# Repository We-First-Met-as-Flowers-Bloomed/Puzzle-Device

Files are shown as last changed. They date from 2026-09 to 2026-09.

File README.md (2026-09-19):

# Puzzle Device｜AI 视觉自动拼图装置

面向 2026 年电子设计竞赛 E 题要求设计的自动拼图实验装置。系统以 MaixCAM2 完成 A4 工作区识别、碎片检测、拼图求解和目标位姿计算，以 STM32F407 完成四轴运动、吸取、旋转和放置。人工完成上电和启动操作后，装置自动执行后续流程。

> 本仓库记录参赛原型的软硬件实现，适合电子设计竞赛复盘、机器视觉与运动控制教学，以及自动控制综合实验参考。实际复现时必须按自己的相机安装位置、机械原点和脉冲当量重新标定。

## 演示视频

项目运行效果已发布到 Bilibili：

- [观看 E 题装置演示与项目动态](https://space.bilibili.com/234483320/dynamic?spm_id_from=333.1387.list.card_title.click)
- 文字说明见 [Demo/README.md](Demo/README.md)

## 系统组成

```mermaid
flowchart LR
    A[上电并等待初始化] --> B[按下 MaixCAM2 启动键]
    B --> C[视觉检测与拼图求解]
    C --> D[生成拾取/放置坐标与旋转角]
    D --> E[UART JSONL 发送至 STM32F407]
    E --> F[四轴运动与电磁铁吸放]
    F --> G{全部碎片完成?}
    G -- 否 --> F
    G -- 是 --> H[声光提示/实验结束]
```

核心模块包括：

- **视觉感知**：检测 A4 纸、分界线和 1—4 块拼图碎片。
- **拼图求解**：计算合法矩形组合、各碎片目标位置和旋转角度。
- **坐标转换**：将相机坐标转换为机构坐标，再转换为绝对脉冲位置。
- **运动执行**：STM32F407 控制 X、Y、Z、R 四轴和电磁铁完成抓取与放置。
- **一键运行**：装置初始化后，由相机端启动键触发一次完整任务。

## 仓库结构

```text
Puzzle-Device/
├── README.md
├── LICENSE
├── Firmware/
│   ├── STM32F407/          # STM32CubeMX/HAL 运动控制工程
│   └── MaixCAM2-Vision/    # AI视觉、拼图求解和坐标输出
├── Hardware/
│   ├── Schematic/          # 嘉立创EDA工程文件
│   ├── PCB/                # PCB资料状态说明
│   └── BOM/                # 元器件清单状态说明
├── Mechanical/
│   ├── STEP/               # STEP资料状态说明
│   └── STL/                # 3D打印模型
├── Docs/
│   ├── System-Design/      # 系统与固件设计资料
│   └── Images/             # 项目图片预留目录
└── Demo/                   # 演示视频入口与操作流程
```

## 快速开始

### 1. 准备工具

- STM32CubeMX 和 Keil MDK-ARM（STM32F407 工程）。
- MaixVision、与设备系统匹配的 MaixCAM2 Runtime。
- 嘉立创EDA专业版（打开 `.eprj2` 工程）。
- 3D 打印机或可读取 STL 的切片软件。
- 3.3 V TTL 串口连接，MaixCAM2 TX/RX 与 STM32 RX/TX 交叉并共地。

### 2. 编译并烧录 STM32F407

1. 进入 [`Firmware/STM32F407`](Firmware/STM32F407)。
2. 可用 STM32CubeMX 打开 `Automatic inspection vehicle.ioc` 查看和重新生成外设配置。
3. 用 Keil 打开 `MDK-ARM/Automatic inspection vehicle.uvprojx`。
4. 选择 STM32F407 对应目标，编译并通过调试器烧录。
5. 首次运动前断开电机负载，检查限位、轴方向、回零逻辑和急停条件。

### 3. 部署 MaixCAM2 视觉程序

1. 进入 [`Firmware/MaixCAM2-Vision`](Firmware/MaixCAM2-Vision)。
2. 将 `config.example.json` 复制为 `config.json`。
3. 使用标定工具生成相机内参和 `frame_to_robot` 变换；确认无误后再设置 `robot_calibrated=true`。
4. 使用 MaixVision 打开整个项目目录并选择“运行项目”，不要只上传 `main.py`。
5. 验证识别和串口输出后，可通过“安装应用”部署，并在设备设置中配置开机启动。

视觉端详细参数、标定命令、UART协议和测试方法见 [MaixCAM2 说明](Firmware/MaixCAM2-Vision/README.md)。

### 4. 接线和联调

1. 保持电机驱动关闭，先验证 MaixCAM2 与 STM32 的串口接线。
2. 使用视觉工程中的 `tools/uart_smoke_test.py` 发送固定测试消息。
3. 检查 STM32 能完整接收一行 JSONL，并确认不会在半包数据到达时启动机构。
4. 分别验证 X、Y、Z、R 轴方向、软硬限位、回零和电磁铁吸放。
5. 低速空载运行完整流程，再安装拼图碎片进行测试。

### 5. 正常操作

1. 放置符合题目范围的 A4 工作区和拼图碎片，确保完整纸边与分界线均在相机画面内。
2. 给装置上电，等待 STM32、驱动器和视觉模块初始化完成。
3. 按下 MaixCAM2 界面中的 `START`。
4. 系统自动识别碎片、规划目标位姿，并依次完成抓取、移动、旋转和放置。
5. 运行过程中不要移动相机、A4 纸或机械结构，也不要进入机构运动范围。

## 关键配置

视觉端默认以 `1280×720`、30 fps 取帧，通过 `/dev/ttyS2`、115200 baud 向主控发送 JSONL。示例动作如下：

```json
{
  "piece_id": 0,
  "pickup_x_pulse": 9600,
  "pickup_y_pulse": 7200,
  "place_x_pulse": 18000,
  "place_y_pulse": 12800,
  "rotation_deg": 30.0
}
```

这些脉冲值仅用于说明协议。更换相机、安装高度、传动机构、驱动细分或机械原点后，必须重新测量并修改配置。

## 资料完整性

当前仓库包含 STM32 与 MaixCAM2 源码、嘉立创EDA工程和三件 STL 模型。PCB Gerber、独立 BOM 和 STEP 模型尚未整理，因此对应目录暂以说明文件占位。欢迎根据原理图和实际装配补充并提交 Pull Request。

## 测试

视觉模块的基础标定测试不需要真实相机：

```powershell
cd Firmware/MaixCAM2-Vision
python -m unittest tests.test_calibration_points -v
```

`tests.test_vision` 中的大部分测试可以直接运行，但部分实拍回归测试依赖未随当前开源包发布的现场图片和本机标定配置，详见 [`tests/README.md`](Firmware/MaixCAM2-Vision/tests/README.md)。STM32 工程的 `tests/` 包含主机端 C 测试和策略检查脚本，可在 Windows/PowerShell 环境按需运行。真实硬件的方向、限位、回零、标定精度和急停仍需逐项实测。

## 开源许可

项目采用 [MIT License](LICENSE)。第三方 STM32 HAL、CMSIS 及其他依赖仍遵循其各自许可证。

## 致谢与交流

如果这个项目对你的电子设计竞赛、自动控制实验或机器视觉学习有帮助，欢迎 Star、Fork、提交 Issue 或 Pull Request。也可以通过上方 Bilibili 页面查看演示并交流复现经验。

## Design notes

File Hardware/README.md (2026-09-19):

# Hardware

`Schematic/` 中提供嘉立创EDA专业版工程文件。当前版本尚未单独导出 PCB Gerber 与正式 BOM；`PCB/` 和 `BOM/` 中的说明用于记录这一资料状态。

制作硬件前请根据所用驱动器、电机、电磁铁、供电和接口定义复核原理图，尤其注意逻辑电平、共地、驱动电流和急停设计。

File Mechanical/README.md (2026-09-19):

# Mechanical

`STL/` 提供当前整理出的齿轮、齿条和约束装置模型，可直接导入切片软件。打印前请根据自己的导轨、同步机构、轴径、公差和材料收缩率检查尺寸。

当前未提供 STEP 装配模型，状态说明见 `STEP/README.md`。

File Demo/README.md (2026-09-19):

# Demo

## 在线观看

[前往 Bilibili 查看 E 题装置演示与相关动态](https://space.bilibili.com/234483320/dynamic?spm_id_from=333.1387.list.card_title.click)

## 演示流程

1. 给装置上电并等待初始化。
2. 在视觉模块上按下启动键。
3. AI视觉模块分析碎片当前位置，求解目标位置与旋转角。
4. STM32 控制四轴和电磁铁依次完成吸取、移动、旋转和放置。
5. 相同过程循环执行，直到所有碎片拼接完成。

演示所用装置针对题目规定的材料、尺寸、数量和工作区条件设计。超出题目范围的碎片、摆放方式或光照条件未作为该原型的能力保证。

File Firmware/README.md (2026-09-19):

# Firmware

- `STM32F407/`：四轴运动、电磁铁、限位、回零、串口协议和任务状态机。
- `MaixCAM2-Vision/`：图像采集、碎片分割、拼图求解、坐标标定和 UART JSONL 输出。

先分别验证视觉输出与各轴运动，再进行串口联调和完整装置测试。

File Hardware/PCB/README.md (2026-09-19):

# PCB

当前开源包尚未提供独立的 Gerber、钻孔和贴片坐标文件。可使用 `../Schematic/STM32F407VGT6-Motion-Control.eprj2` 在嘉立创EDA专业版中查看现有工程并按实际版本导出。

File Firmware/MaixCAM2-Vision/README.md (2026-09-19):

# MaixCAM2 E 题拼图视觉

当前版本：`0.2.48`

白色自备碎片和白底扑克牌会先尝试经过数量、面积及 3～5 边形
规则验证的快速 Lab 分割；不满足条件的彩色碎片、低饱和度纸面或
复杂光照场景自动使用原有的自适应光照平面分割。

这套代码完成以下板端视觉链路：

1. 自动检测完整 A4 外轮廓并做透视校正；
2. 在 Lab 颜色空间检测规定的中部分界线；
3. 自动把有碎片的一侧旋转为纸面坐标的上半区；
4. 用纯色 A4 的背景模型分割 1–4 片直边碎片；
5. 提取多边形、质心和距离边界最远的稳定吸取点；
6. 先按边长、端点补角和直角/外边界先验建立候选图，枚举四片的全部全局连接树，再用 T 接点搜索补充；
7. 支持完整共边、长边内部偏移和一条长边被多片分段拼接的 T 接缝；
8. 自动区分纯色片与印刷片，只对扑克牌用跨接缝 Lab 颜色/梯度连续性消歧；
9. 把矩形居中放入 A4 下半区安全范围，输出每片吸取点、放置点和旋转量；
10. 可选地把 A4 毫米坐标映射为运动机构毫米坐标，并通过 UART 输出 JSON。

算法不需要网络、电脑端推理、AprilTag、额外定位线、补光或遮光板。比赛运行时只使用
MaixCAM2、板载 OpenCV/NumPy、A4 边界、规定分界线和碎片本身。

## 目录

```text
main.py                         MaixCAM2 横屏触控运行入口
config.json                     板端安全默认配置
config.example.json             参数与坐标标定示例副本
puzzle_vision/detector.py       A4、中线、背景和碎片检测
puzzle_vision/template_solver.py 图 2 固定四片的有界模板求解
puzzle_vision/solver.py         几何搜索及扑克牌接缝评分
puzzle_vision/pipeline.py       目标落位、指令输出和可视化
tools/run_image.py              PC 端回放一张实拍图
tools/calibrate_camera.py       赛前镜头内参标定
tools/collect_calibration_points.py 鼠标点选像素并录入机构坐标
tools/fit_frame_to_robot.py     固定相机像素到机构坐标标定
tools/uart_smoke_test.py        UART2 固定 JSON 发包测试
tests/                          图 2、透视和横向摆纸合成测试
```

## 0.2.48 扑克牌求解轮廓的毫米级稳定化

- 扑克牌检测结果仍保留原始毫米坐标、吸取点和面积；仅送入组合求解器的多边形顶点取整到 1 mm，消除相邻帧约 0.3～0.7 mm 的轮廓抖动。
- 本次 Q♠ 连续两帧由“一帧成功、一帧两轮失败”恢复为稳定的唯一矩形候选。

## 0.2.47 固定红纸的阴影粘连抑制

- 固定标定且纸面颜色饱和时，完整分割改用色度差作为前景，避免只有亮度变化的红纸阴影与真实碎片粘连。
- 本次 Q♠ 实拍中的 2908 mm² 贴边伪五边形恢复为独立真实碎片，防止两轮求解在错误轮廓上耗尽时间。

## 0.2.46 固定纸框外边缘伪碎片过滤

- 当颜色分割产生超过 4 个有效多边形时，优先去除贴住纸张上、左、右外边界的光照区域；只有过滤后仍得到 1～4 片才采用该结果。
- 本次 Joker 实拍中的两个右边缘伪轮廓被去除，真实四个碎片保持不变。

## 0.2.45 三片拼图的二次 T 接缝搜索

- 三片扑克牌首次通用搜索失败后，现在会进入二次覆盖搜索，不再把 1～3 片一律视为无需重试的确定性路径。
- 两片已经放置后，三片模式也会按局部轮廓紧凑度筛选扩展的 T 接缝候选，避免正确的长边内部拼接被候选上限截掉。
- 本次 3 片 6♣ 实拍保持原检测轮廓，状态由 `SolveError` 恢复为 `OK`；PC 端检测加两轮求解约 `0.6 s`，有效候选为 1。

## 0.2.44 三片扑克牌的双切边印花恢复

- 修复 `expected_piece_count=0` 时，白色快速分割把两个有效轮廓当作完整结果返回、忽略第三个
  “面积达到碎片范围但因双切边印花而未通过多边形修复”的轮廓。现在只要存在这种被拒绝的
  碎片大小连通域，就回退到包含黑色牌面图案的完整 Lab 颜色分割。
- 本次 3 片 10♠ 实拍由错误的 2 片恢复为 3 片，面积约为 `1240、1849、2154 mm²`；
  通用求解只需约 `65 ms`，填充率约 `0.955`、四边覆盖约 `0.950`。
- 通用求解的最终候选改用已有的全局刚体等价判断去重。同一相对装配仅因整体平移/旋转不同
  不再被当成两个低分差答案；目标落位仍会在下半区统一居中，真正不同的片间相对关系不会合并。
- 实拍端到端状态由 `ERROR/LOW_MARGIN` 恢复为 `OK`；上一版四条 8♠ 强阴影回归仍为 `OK`，
  分差约 `0.077`。当前可执行视觉测试为 74 项通过、标定测试为 3 项通过，另有 10 项
  历史实拍测试因 `tests/data` 原图缺失而未执行。

## 0.2.43 全切边印花条带与强光阴影分离

- 修复四条扑克牌的每条切边都被黑色花色切出缺口时，白色牌面快速分割被整体放弃的问题。
  旧路径随后会把右上强光/阴影区域拟合成约 `7943 mm²` 的假五边形，并漏掉真正的第四条牌片。
- 仅当白色掩膜得到 4 个同宽、总高符合整牌比例的条带，而且四个轮廓都需要印花缺口修复时，
  才用各条带的最小外接矩形恢复物理切边；普通不规则碎片和正常实测轮廓仍沿用原路径。
- 给这类重建边界增加显式标记。专用条带求解仅对标记后的轮廓从边界内侧 `3..5 mm`
  采样接缝纹理，避免误读矩形外的红纸；其他牌片继续使用原来的 `1..3 mm`，防止全局参数回归。
- 本次 8♠ 原图由两轮通用搜索失败恢复为 `OK`：正确检出 4 个约 `1139..1448 mm²`
  的矩形条带，只评估 384 个牌面顺序，PC 检测加求解约 `1.64 s`，分差约 `0.077`。
- 新增全切边缺口的合成回归；当前可执行视觉测试为 73 项通过、标定测试为 3 项通过，
  另有 10 项历史实拍测试因 `tests/data` 原图缺失而未执行。

## 0.2.42 固定标定碎片总面积容差一致化

- 修复固定纸面标定的最终面积校验比候选预检和完整分割验证更严格的问题：原先其范围为
  目标面积的 `85%..115%`，其余两处均为 `75%..125%`，导致同一画面在固定机位路径反而被提前拒绝。
- 板端本次测得的 `14695 mm²` 高于旧上限 `13656 mm²`，但低于统一后的上限 `14844 mm²`，
  因此现在可以继续进入碎片几何与求解验证，而不会在固定标定入口误报 `DetectionError`。
- 新增固定标定合成回归，复现 `14557 mm²` 的同区间场景；当前可执行视觉测试为 72 项通过，
  标定测试为 3 项通过，另有 10 项历史实拍测试因 `tests/data` 原图缺失而未执行。

## 0.2.41 论文驱动的四条扑克牌重组

- 四个同宽矩形条带不再进入通用 C1/C2 几何搜索。新分支先把每条牌片校正到局部坐标，
  为每个方向建立有向相邻边代价矩阵，再组合整牌顺序；普通随机多边形、Figure-2 和纯色碎片路径不变。
- 接缝代价采用双向一阶边界预测与沿切口方向的梯度连续性，并允许 `±2 mm` 的只读采样偏移；
  绝对误差再按每条源边和目标边的四分位数归一化，避免空白白边天然压过真正的印花连续边。
- 把互为最近邻的接缝作为 `best-buddy` 可靠性证据，同时检查牌面两个角码是否位于对角。
  最终只需评估 `4!×2^4=384` 个由相邻边矩阵评分的整牌顺序；矩形几何只负责硬验收，不再主导牌面排序。
- 两张当前可用的 8♠ 现场原图均返回 `OK`：此前 `LOW_MARGIN` 的一张分差由 `0` 提高到约 `0.075`，
  另一张保持正确顺序且分差约 `0.105`；PC 检测加求解约 `0.9–1.8 s`，均为 384 个轻量顺序。
- 方法依据包括 Pomeranz 等人的预测兼容度与四分位归一化、Gallagher 的梯度兼容度、
  Son 等人的方向导数兼容度，以及条带碎纸重组的有向代价矩阵：
  [CVPR 2011](https://www.cs.bgu.ac.il/~ben-shahar/Publications/2011-Pomeranz_Shemesh_and_Ben_Shahar-A_Fully_Automated_Greedy_Square_Jigsaw_Puzzle_Solver.pdf)、
  [CVPR 2012](https://chenlab.ece.cornell.edu/people/Andy/Andy_files/Gallagher_cvpr2012_puzzleAssembly.pdf)、
  [CVPR 2016](https://openaccess.thecvf.com/content_cvpr_2016/html/Son_Solving_Small-Piece_Jigsaw_CVPR_2016_paper.html)、
  [CVPR 2020 论文与代码](https://github.com/thiagopx/deeprec-cvpr20)。
- 当前工作区可执行的 71 项视觉测试和 3 项标定测试全部通过；另有 10 项历史实拍测试因
  `tests/data` 图像未保留在当前工作区而无法执行。两张本轮现场原图已单独完成端到端回放。

## 0.2.40 固定纸面标定、面积自适应落位与复杂牌面精修

- 当前固定相机直接使用 `config.json` 中实测的 `fixed_paper_quad_px`：
  `[(398.55,27.0), (1124.65,27.35), (1100.8,543.42), (392.73,538.18)]`。
  每轮不再重新猜测红色 A4 外框，也不使用黑色中心线决定纸框或朝向；校正后的分界线固定为纸面中心。
  若相机、镜头、分辨率或红纸位置发生移动，必须重新测量这四点，不能继续沿用旧坐标。
- 放置外扩量由统一 `3 mm` 改为面积自适应：
  `3*sqrt(四片面积中位数/当前片面积)`，并限制在 `2..5 mm`。小片获得更大装配余量，
  大片保持更接近理论位置；等面积切片仍为 `3 mm`。
- 求解搜索按碎片面积从小到大扩展，优先利用小片较强的接缝约束来压缩候选；
  机械执行则按面积从大到小放置，先建立稳定基准，最后填入小片，避免后放的大块扫动已落位小块。
- 第二轮对 J/Q/K/大小王等复杂牌面使用与首轮不同的 `2.5 mm` 缝线共线容差，并对已接近矩形的
  完整拓扑执行有界平移/旋转坐标下降；精修后仍须重新通过填充、重叠、孔洞、边界、四边覆盖、
  凸性和四角误差的严格验收，不以“看起来像矩形”代替资格检查。
- `E:\桌面\figures` 中 Q、大小王、K、J 四张 `1280×720` 实拍原图已固化为自动回归：
  均稳定检出 4 片并返回完整解；本轮可执行回归为 77 项全部通过，另有 7 项历史现场测试因其旧图片
  不在当前工作区而未执行。

## 0.2.39 四条扑克牌整牌排序与纸张候选修复

- 修复 1280×720 输入被先缩到 1100 像素、再缩到约 1 px/mm 预检时，窄牌片消失的问题；
  A4 候选的几何检测仍在有界缩略图上运行，但碎片数量/面积预检改用原始帧像素。
- 避免把黑色分隔线左侧的半张红纸误认成完整 A4；最新 8♠ 实拍由错误的约 294 px
  半纸宽恢复为约 740 px 整纸宽，中线覆盖率由 `0.29` 回升到 `0.63`。
- 新增四条同宽、不要求等面积的扑克牌分割识别。此类候选不再只按局部接缝或矩形外形排序，
  而是使用整牌 180°对应关系、对角角码和中心花色布局评分。
- 条带牌片的均衡种子容量由 6 提高到 24，覆盖四条的正确相邻关系；整牌特征权重提高到
  `0.60`。若最佳矩形的整牌特征仍不成立，则强制返回 `LOW_MARGIN`。
- 最新 8♠ 现场帧 PC 端检测加求解约 `1.6–1.8 s`，求解 170 个节点，分差约
  `0.202`；新增真实帧和不等高合成条带回归。

## 0.2.38 四等分扑克牌整牌特征求解

- 新增四等分扑克牌识别：仅当四块均为近似矩形、面积比不超过 `1.18`、对应边长差不超过
  `15%` 时启用专用路径，不改变普通随机切片和纯色拼图。
- 不再接受第一个几何矩形。专用路径去除整牌 180°全局等价后，有界枚举 192 种象限与朝向
  组合，并按整张牌面的归一化 Lab 印刷特征排序。
- 整牌判据同时使用跨象限图案、180°对应关系、对角角码分布，以及中心花色相对扑克牌长轴
  的方向；牌面权重只在四等分专用路径中提高。
- 若所有排列都只能拼出矩形、但牌面图案本身无法区分，`score_margin` 会低于默认 `0.012`，
  管线返回 `LOW_MARGIN`，不会向运动主控下发任意排列。
- 192 种布局先做稀疏整牌评分，仅对前 12 个执行严格栅格矩形验收；合成样例 PC 求解约
  `0.52–0.62 s`。
- 7 张既有现场帧全部保持成功，PC 总耗时为 `0.582–0.859 s`；完整回归现为 80 项。

## 0.2.37 放置碎片向外扩散 3 mm

- 每片最终放置点相对拼接矩形中心的径向外扩量由 `1 mm` 调整为 `3 mm`，用于进一步避免
  相邻碎片发生重叠；原始吸取位置和 `rotation_deg` 均不变。

## 0.2.36 二次求解的轮廓与位姿图恢复

- 主路径保持 v0.2.35 的实测轮廓和候选顺序；只有首轮四片扑克牌求解失败后，恢复轮才用
  稠密轮廓上的直线支持做稳健 TLS 拟合，并以相邻直线交点恢复被圆角、缺口或模糊吞掉的
  虚拟直角。锐角、弱支撑、拓扑改变和面积误差过大的拟合会自动回退。
- 恢复轮对 C1/C2 相对位姿增加三片闭环一致性软奖励；
  `T(i,j)·T(j,k)` 越接近直接候选 `T(i,k)`，种子优先级越高。无闭环的树形拼图保持中性，
  不做硬过滤；批量矩阵计算避免挤占板端搜索预算。
- 修复恢复多边形与碎片面积不同步的问题：仅把虚拟尖角带来的面积增量加入原始实测面积，
  不会把全部轮廓面积错误替换为 RDP 多边形面积。
- 7 张此前上传的 1280×720 现场原始帧全部直接回放成功；PC 总耗时为
  `0.558–0.930 s`，填充率为 `0.924–0.959`，洞率为 `0–0.013`。
- 完整回归现为 78 项。

## 0.2.35 恢复轮长边内部位置扩展

- 首轮的 C1/C2 候选数量和矩形验收标准保持不变；只有首轮失败后，恢复轮才把由全部已测
  边长推导出的长边内部拼接位置从 2 个扩为最多 8 个，并为每组边配对保留前 4 个。
- 修复了候选位置受碎片编号顺序影响的问题：正确的长边内部位置即使是第 3～8 个推导值，
  也能进入第二轮配准图。新增合成难例证明首轮仍拒绝该位置、恢复轮能精确保留。
- 强制让 7 张真机扑克牌帧全部走恢复轮，均返回完整解；PC 总耗时为
  `0.776–1.145 s`，恢复轮节点数为 `504–1962`，明显低于板端 15/30 秒预算。
- 完整回归现为 76 项。

## 0.2.34 无遮挡纸面重标定

- 使用机械臂移开后的完整纸面重新拟合四条直边；16 个规则十字展开后的列坐标误差小于
  `0.4 mm`、单点行坐标误差不超过约 `1.2 mm`。
- 原点和通信约定不变：左上角 `(0,0)`，X 向右 `0..24000 pulse`，
  Y 向下 `0..16700 pulse`，`80 pulse/mm`，`rotation_deg` 为顺时针角。

## 0.2.33 边界与十字阵列双重标定

- 根据最新固定相机原图重新拟合红纸四条长边，以直线交点避开左上角机构遮挡和右下角线缆；
  新矩阵同时通过纸面 4×4 十字阵列的直线性及等间距检查。
- 原点、脉冲范围和旋转定义不变：左上角 `(0,0)`，X 向右 `0..24000 pulse`，
  Y 向下 `0..16700 pulse`，`80 pulse/mm`，`rotation_deg` 为顺时针角。

## 0.2.32 新机位重新标定

- 按最新固定相机画面重新拟合红纸四条边界，并更新 `frame_to_robot`；映射范围仍为
  X `0..24000 pulse`、Y `0..16700 pulse`，脉冲当量仍为 `80 pulse/mm`。
- 原点、轴方向和旋转定义均不变：红纸左上角为 `(0,0)`，X 向右、Y 向下，
  `rotation_deg` 为 `[0,360)` 内的顺时针相对旋转角。

## 0.2.31 左上原点与 X 向右

- 按当前固定相机画面重新标定红纸区域：红纸左上角为 `(0,0)`，长边 X 正方向从左向右，
  对应 `0..24000 pulse`；短边 Y 正方向从上向下，对应 `0..16700 pulse`。
- `rotation_deg` 的定义不变，仍为 `[0,360)` 内的顺时针相对旋转角。

## 0.2.30 串口旋转角统一顺时针

- UART 的 `rotation_deg` 统一为 `[0,360)` 内的顺时针相对旋转角；原来的负角会转换为
  等价顺时针角，例如 `-45.5°` 发送为 `314.5°`。
- `rotation_deg=0` 仍表示无需旋转，不会为了满足正数形式而空转一整圈。

## 0.2.29 双轮求解与 30 秒总截止

- 单轮求解上限由 `6000 ms` 调整为 `15000 ms`；首轮抛出 `SolveError` 或只得到未完成的 `SEARCH_LIMIT` 候选时，直接复用已经识别出的纸面和四块轮廓进行第二轮求解。相机采集、A4 检测和碎片分割不会重复执行。
- 两轮求解共用 `solver_total_time_limit_ms=30000` 的绝对预算。第二轮只能取得扣除首轮实际耗时后的剩余时间，不会简单地再获得完整 30 秒；首轮正常完成时不会启动第二轮。
- 恢复轮不是原样重跑：扑克牌补查首轮跳过的全局连接树，种子覆盖扩大到 48 个，每组检查前 4 个配对变体及前 8 个跨组关系；纯色四片则跳过首轮已完成的全局树，集中补查扩展配对路径。纹理评分和矩形资格保持不变。
- 若恢复轮失败但首轮已有合法的未完成候选，保留首轮 `SEARCH_LIMIT` 结果；两轮均无候选时合并报告两次失败原因。最新梅花牌强制跳过首轮后，恢复轮于 452 节点返回 `OK/search_complete=true`。
- 完整回归现为 74 项。

## 0.2.28 全边印花轮廓与双组复排

- 最新梅花牌实拍中，四块的黑色印花都与切边相接。快速白片掩膜把四条真实边同时切出凹口，原轮廓均需超过基础值 4 倍的拟合误差；对所有碎片强制凸包后，离线完整搜索至 102785 节点仍无合法矩形。
- 快速白片候选现在只有在至少一块保留稳定原轮廓时才被采用；若全部合法组件都需要粗拟合，则回退到已有的自适应光照平面分割，保留黑色印花像素。前六张实拍仍走原快速路径，颜色阈值和矩形资格没有放宽。
- `2+2` 阶段复用最终 24 个种子已经计算出的外边/直角复排结果，每个碎片对组选前两个、每条跨组关系取前五个。最新帧离线于 246 节点返回 `OK/search_complete=true`，`fill=0.924`、`side=0.934`、`hole=0.013`、边界 `3.7/4.1 mm`。
- 完整回归现为 73 项。

## 0.2.27 四边形牌片的接缝证据继承

- 新实拍的四片均为四边形，正确双片种子已经排在第 1 位，但三片状态重新计算紧凑度时丢弃了父种子的强接缝证据；正确解离线要到约 2922 节点才首次出现，完成复核共需 3114 节点，而实机 6000 ms 内只搜索到 768 节点。
- 四个四边形现在只保留六个无序碎片对各自的最强种子，不再复排同一碎片对的额外变体；三片及四片状态保留 75% 的父接缝优先级。该路径没有增加几何计算，其余含三角形/五边形的牌面仍使用原来的 24 个种子和原排序。
- 全四边形路径首个合法解后的固定复核量为 96 个节点；该帧现于 756 节点返回 `OK/search_complete=true`，`fill=0.959`、`side=0.983`、`hole=0`。时间上限和矩形资格均未放宽。
- 完整测试发现现为 72 项。

## 0.2.26 牌面切边印花缺口修复

- 新实拍中两片牌面轮廓需要把多边形拟合误差从默认 `0.7 mm` 放大到 `10.19 mm` 才能压到 5 个顶点。黑桃印花恰好与物理切边相接，被白片掩膜误当成大凹口；求解多边形因此丢失约 `400 mm²`，完整搜索的最佳候选仍只有 `fill=0.921 / hole=0.032`。
- 纹理轮廓现在仅在原拟合误差超过基础值 4 倍时检查已有的安全凸包；凸包仍必须增加不超过 20% 面积，并且确实降低多边形拟合误差。正常 3～5 边形、纯色片和真实拐角继续使用原轮廓。
- 该帧修复后最大拟合误差降至 `2.67 mm`，标准阈值下于 814 节点返回 `OK/search_complete=true`，`fill=0.950`、`hole=0`、最小边覆盖率 `0.977`。牌面首个合法解后的固定复核量由 384 个节点缩至 192 个，低于本轮实机 964 节点的已测吞吐量；没有提高 `6000 ms` 时限或放宽矩形资格。
- 完整回归现为 68 项。

## 0.2.25 板端轻量种子复排

- 最新实机帧正确检测 4 片，但 v0.2.24 对最终 24 个种子补做完整接触评分后，板端到 `5.2 s` 只搜索 1649 个节点；此前同机同期可搜索约 3200 个节点。瓶颈是复排本身的接触追踪，而不是正确解被过滤。
- 100 多个原始种子继续使用快速评分；最终 24 个种子现在只补算已有的矩形外边界直线和直角支撑，不再调用完整的片间接触追踪。新增 `[vision] selected card seeds reranked in ... ms` 日志，可直接核对实机复排耗时。
- 最新实拍离线节点数由纯快速排序的 5523 降至 3266；上一张重复拍摄帧由 6002 降至 1995。原有相邻尖角、细内接缝实拍回归也全部通过，没有提高 `6000 ms` 时限或放宽矩形资格。
- 完整回归现为 67 项。

## 0.2.24 重复拍摄的种子排序稳定性

- 同一摆法连续拍摄时，第一次在实机 1735 节点成功，第二次因轻微轮廓抖动在 4027 节点超时。离线确认第二帧的正确解没有丢失，但要到约 5600 节点才首次出现，完成固定复核后共需 6002 节点。
- 正确双片接缝仍在按碎片对保留的 24 个种子中；问题是轻量紧凑度把它排在多个错误分支之后。现在仍对 100 多个原始种子使用快速评分，仅对最终确定入队的 24 个扑克牌种子补做已有的外边、直角和接触完整评分。
- 第二次实拍现于 2372 节点返回 `OK/search_complete=true`；前两张实拍也分别约为 2300 和 2331 节点。节点数均低于本轮实机 4027 节点的已测吞吐量，没有提高 6000 ms 时限或放宽矩形资格。
- 完整回归现为 66 项。

## 0.2.23 扑克牌细接缝外轮廓修复

- 新实拍帧已正确检测 4 片，但拼合后不足 `1 mm` 的测量接缝仍在求解栅格上与外界连通；外轮廓提取会沿细缝进入矩形内部，把内接缝误算为边界缺口，导致 `boundary p95/p99=9.0/11.5 mm` 并拒绝正确候选。
- 矩形指标现在先闭合一个求解栅格像素的细缝，再提取外轮廓；连通性、精确多边形面积、重叠率、颜色阈值和原有 `8/10 mm` 扑克牌容差均未放宽。
- 同一实拍候选修正为 `boundary p95/p99=5.8/8.3 mm`，填充率 `0.948`、最小边覆盖率 `0.983`。
- 扑克牌找到首个合法候选后的固定复核量由 1000 个节点缩至 384 个；纯色几何搜索仍保留原来的 1000 个。该帧现于 3815 节点完成，在实机日志已达到的 4034 节点以内返回 `OK` 和完整运动指令。
- 完整回归现为 65 项。

## 0.2.22 相邻扑克牌碎片分离

- 实拍四片中有两片尖角几乎接触，原来的快速白片掩膜把它们桥接成一个五边形，因而只检测到 3 片。清理掩膜的开运算现在按纸面毫米尺度取整：默认 `3 px/mm` 下由 `3×3` 调整为 `5×5`，只去除亚毫米连接，闭运算、颜色阈值和合法碎片尺寸规则均保持不变。
- 新增该 `1280×720` 原始相机帧回归。正式离线回放可稳定得到 4 片（3、3、3、4 个顶点）并完成通用求解，填充率约 `0.955`、最小边覆盖率约 `0.967`。
- 全局连接图现在先检查节点/时间上限，再接受高置信度矩形；未完成的受限搜索不会被误报为完整解。
- 完整回归现为 64 项。

## 0.2.21 扑克牌失败页保留原相机画面

- 原图叠加不是按碎片类型分流；此前扑克牌截图仍显示竖向 A4，是因为本轮发生 `SolveError`，成功结果图尚未生成，而异常页仍优先使用旧的校正图。
- 检测完成后现在额外缓存原相机帧检测叠加图。后续即使 Figure-2、通用碎片或扑克牌求解失败，错误页也保留完整现场画面、A4、中线、实测碎片轮廓和吸取点。
- 求解失败时没有合法目标位姿，因此不会伪造目标矩形；只有 `OK/LOW_MARGIN/SEARCH_LIMIT` 等管线正常返回结果时才绘制目标轮廓、放置点、旋转角和抓放箭头。
- 新增 `/maixapp/tmp/puzzle_detected_frame.jpg`，同时保留竖向校正检测图 `puzzle_detected.jpg`；完整回归现为 63 项。

## 0.2.20 物理横屏方向与原图位姿叠加

- 实机照片确认 MaixCAM2 LCD 报告 `480×640`，并把横屏缓冲区顺时针旋转到物理屏幕；显示前现在自动逆时针预旋转，触控坐标同步做逆变换，三个按钮和相机画面不再整体侧转。
- 求解结果不再用竖向透视校正 A4 图替换相机画面；现在保留求解前的完整相机帧，并把 A4 外框、中线、源碎片轮廓、吸取点、目标矩形、放置点、旋转角和抓放箭头反投影到原图。
- `puzzle_debug.jpg` 和 PC 回放输出均为原相机尺寸的位姿叠加图；内部竖向 A4 调试图仍单独保存为 `puzzle_debug_raw.jpg`，检测、求解和机构坐标数值没有改变。

## 0.2.19 横屏结果与屏幕触控

- 相机预览、检测结果、求解结果和错误页统一装入与相机同方向的横屏画布；例如输入是 `720×480`，输出仍是 `720×480`，不会再把内部 `630×891` 的 A4 校正图直接显示成竖屏。
- 默认 `start_mode=touch`，屏幕底部提供 `START`（开始一轮）、`STOP`（立即标记取消并丢弃本轮结果）和 `RESET`（清除结果并恢复实时预览）三个触控按钮，不再依赖 FUNC 键；求解放在后台线程，运行期间按钮仍可响应，已取消的后台计算会安全收尾且不会通过 UART 下发。
- 触控坐标会反算 `Display.show(FIT_CONTAIN)` 的缩放和黑边；即使驱动报告 `480×640`，按钮仍按实际横屏画面命中。
- `puzzle_debug.jpg` 保存为相机方向的横屏结果，原始竖向 A4 调试图另存为 `puzzle_debug_raw.jpg`，视觉坐标和运动位姿计算不变。

## 0.2.18 板端增量节点加速与诊断

- 同组五红桃历史实拍图能稳定求解，但需要约 1256 个增量节点；v0.2.17 的实机在 6 秒内只能处理 512 个，因此当前失败是板端节点吞吐量不足而不是几何无解。
- 扑克牌未完成状态不再提前计算成品才需要的外边、四角和全部接触指标；同一碎片对、同一相对刚体位姿的重叠面积会跨搜索路径缓存，避免重复调用 OpenCV 多边形相交。
- 超时前新增 `depth/complete states/overlap cache` 统计；若已产生四片状态，错误信息会同时报告最接近候选的 `fill/side/convexity/corner/boundary/overlap/hole`。

## 0.2.17 扑克牌 T 接点优先调度

- v0.2.16 已使全部准备阶段在时限内结束；新日志显示 256 状态图和 384 个 `2+2` 均保留 0 个结果，而真正的增量搜索只剩约 2 秒、397 个节点。
- 确认有印刷纹理且恰好四片时，跳过多轮实机均无最终结果的宽图预检；`2+2` 只检查 48 个最强组合，把主要预算交给支持分段长边的 T 接点搜索。
- 扑克牌双片队列由 12 增至 24，确保每个无序碎片对可覆盖约 4 个候选，处理实测中正确接缝局部排名低于前三的情况。纯色通用碎片仍使用 1024 状态图、12 个高质量种子和完整 `2+2`。

## 0.2.16 双片种子轻量排序

- v0.2.15 已把扑克牌全局预检限制为 256 状态，但实机仍只来得及检查 16 个 `2+2` 位姿；由此确认 174 个双片种子的完整 `_partial_priority` 是新的主要耗时。
- 双片尚不是成品矩形，现在只按包围框紧凑度、尺寸和原始 C1/C2 名次轻量排序，不再逐个计算完整外边覆盖、角点及所有轮廓接触。
- 四片候选仍执行原有严格矩形资格和扑克牌纹理连续性评分。日志新增双片种子与 `2+2` 阶段毫秒耗时，便于继续按实机数据定位。

## 0.2.15 扑克牌分阶段搜索预算

- v0.2.14 日志显示全局图完成 1024 状态后，`2+2` 仅来得及检查 16 个交叉位姿，说明 6 秒预算仍过度集中在前置图阶段。
- 四片扑克牌现在只用 256 个全局树状态做快速预检，把剩余预算交给双片种子、`2+2`、T 接点和纹理连续性评分；纯色通用碎片仍执行完整的 1024 状态全局图。
- 只改变各阶段的计算预算，不改变候选深度、矩形资格、轮廓容差或纹理权重。新增四片印刷图案通过 256 状态预检后继续完成 `2+2` 求解的回归。

## 0.2.14 扑克牌 2+2 种子去重

- v0.2.13 已让 1024 个全局树状态在时限内完成；新日志表明剩余瓶颈转移到 `2+2` 双组种子的准备阶段。
- 正反方向的相同双片位姿现在会在轮廓接触评分之前归并；实测扑克牌回归由 348 个有向位姿归并为 160 个唯一种子，同时仍保留每条边前 4 个候选。
- 两个双片组刚性合并后，包围框只计算一次，并只检查两个组之间的四组交叉重叠；每个双片组内部已经验证过的接缝不再重复检查。最终严格矩形和纹理评分保持不变。

## 0.2.13 扑克牌全局图去重

- Figure-2、通用碎片和扑克牌继续共享同一套核心矩形资格检查，但保留各自必要的拓扑、轮廓噪声和纹理参数；不会把固定模板的专用容差直接套到未知扑克牌上。
- 扑克牌日志中的 `kept 1 complete layouts` 只是通过增量检查的完整假设，并不代表已经通过最终矩形检查；此前 1024 个树组合重复计算相同的部分位姿，耗尽 6 秒后还没进入纹理阶段。
- 全局树现在按“新加入碎片 + 已放置位姿”缓存中间尺寸/重叠结果；仍保留每条边前 4 个 C1/C2 候选和相同最终排序，不重现只留前三而丢失实测扑克牌真解的问题。

## 0.2.12 Figure-2 单边轮廓掉点

- 新一轮实拍的唯一失败项为 `side=0.504`；同时 `fill=0.941, overlap=0.002, hole=0.005, convexity=0.977, corner=4.0 mm, boundary=6.0/12.0 mm`，证明整体仍是高质量矩形候选。
- 已严格匹配 Figure-2 时，单条外边覆盖率下限由 `0.55` 改为 `0.40`，覆盖实拍中某一侧因透视校正和多边形简化造成的局部掉点。历史错误布局的 `side=0.268/0.038` 仍会拒绝。
- 通用现场碎片和扑克牌继续要求配置中的 `side>=0.88`；新增本轮完整指标回归，并验证固定模板 `side=0.399` 仍不通过。

## 0.2.11 Figure-2 轮廓重叠抖动

- 新一轮实拍中固定四片已严格匹配，矩形的填充、孔洞、四边、凸度、四角、边界和尺寸也全部合格，唯一失败项是计算轮廓随拍摄帧从 `overlap=0.003` 抖动到 `0.025`。
- 只对已严格确认的 Figure-2 快速模板把计算重叠率上限设为 `0.030`；通用现场碎片和扑克牌仍使用配置中的严格上限，不会因此放过普通非矩形候选。
- 新增本轮完整指标回归，并验证 `overlap=0.031` 仍会被拒绝，避免后续继续无边界地放宽。

## 0.2.10 Figure-2 实拍抖动容差

- 针对同一套自备碎片连续拍摄时的轮廓量化抖动：只有在四片形状已严格匹配 Figure-2，且重叠、孔洞、边界、凸度、连通性和目标尺寸均合格时，快速模板才允许 `fill>=0.92`、`side>=0.55`、`corner<=6 mm`。
- 最新实拍日志中的 `fill=0.926, overlap=0.003, hole=0.005, side=0.573, convexity=0.973, corner=5.2 mm` 现在会直接通过快速模板，不再错误落入通用搜索；比赛现场随机碎片和扑克牌的通用矩形阈值完全不变。
- 通用求解的 `2+2` 种子准备改为每组只保留前 8 个候选，并在生成过程中持续检查截止时间；`6000 ms` 到期后不会再因为一次昂贵的种子组合拖到约 12 秒。

## 0.2.9 黑色中线与板端预算

- 中线不再只比较某一行的异色像素比例；现在联合使用距纸面 Lab 色差、相对暗度、细线局部对比、横向连续范围、线宽和几何中心先验。
- 支持手画黑线存在少量断笔和上下波动，并抑制长碎片边、宽阴影及远离纸张中点的伪直线；低置信度时安全回退到 A4 几何中点。
- 日志新增 `divider y=... mm, coverage=..., source=measured/center-fallback`，便于现场直接判断中线是否选对。
- 四片全局图的每条树边由 6 个候选降为 4 个，最坏状态数从 3456 降至 1024，为 MaixCAM2 的 T 接点搜索保留时间。
- 严格匹配 Figure-2 且填充、重叠、孔洞、边界、凸度、四角和尺寸均合格时，固定模板外边覆盖率允许到 `0.62`；通用现场碎片和扑克牌仍保持原有严格阈值。

## 0.2.8 同面全局配准图

- 所有碎片只允许平移和旋转，输出变换的行列式必须为正；铁片在背面的题目条件下不再把模板残差解释成“碎片翻面”，也绝不靠软件反射伪造解。
- 吸收图优化拼图算法的“冗余局部配准、全局组合裁决”思路：四片时枚举全部 16 棵标号生成树，每条树边保留 6 个 C1/C2 候选，最多检查 3456 个全局状态。
- 全局图阶段直接检查完整矩形的填充率、重叠、孔洞、四边覆盖、凸度、四角和尺寸；高置信解立即返回，其他合格解继续交给 T 接点路径择优。
- 固定 Figure-2 若只能闭合内部接缝、却不能形成严格矩形，会明确报告同面接点误差及 `fill/side/corner`，随后尝试通用求解；不会把非矩形结果标成成功。
- 扑克牌仍在全部几何合格候选之间用跨接缝纹理连续性消歧；纯色自备片不会承担这项开销。

## 0.2.6 Figure-2 双布局择优

- 每个 Figure-2 形状映射同时评估独立刚体布局和拼缝锁定布局；不再因为严格形状匹配成功而跳过更适合实物裁剪误差的布局。
- 两套布局都先通过完整矩形资格检查，再选择几何误差较小者；不会用放宽矩形阈值来掩盖拼接错误。
- 模板失败日志改为报告所有已检查布局中最接近矩形的候选，并标明 `independent` 或 `seam-locked`，不再显示容易误导的第一个候选。

## 0.2.5 Figure-2 外边覆盖容差

- 已确认 Figure-2 且其他矩形指标全部合格时，最差外边覆盖率下限
  使用 `0.75`；通用现场碎片和扑克牌仍使用配置中的 `0.88`。
- 覆盖本次板端日志的 `side=0.798`，同时继续拒绝低填充的非矩形
  实拍回归。

## 0.2.4 Figure-2 官方顶点容差快路

- 已确认是题图固定四片、且填充率、孔洞、重叠、四边覆盖、凸度、
  四角和尺寸全部合格时，碎片之间的小栅格缝隙按题目 20 mm
  对应顶点上限验收，不再误入板端通用搜索。
- 模板拒绝日志补充 `boundary=P95/P99` 和 `components`，以后不会再
  隐藏真正失败的条件。
- 低填充或明显非矩形的候选仍然拒绝；这一放宽不适用于比赛现场
  随机切法和扑克牌的通用求解。

## 0.2.2 快速通用求解与矩形资格审查

- 保留固定图 2 的快速模板路径；不匹配时自动进入通用求解，不再把所有切法硬套一个模板。
- 吸收双片优先、外轮廓链和矩形直角先验：从最可信的双片接缝开始，并按外边覆盖率和四角支持度排序。
- 双片种子按碎片对分桶保留，避免同一条错误接缝占满候选；四片任务额外尝试有界 `2+2` 双组拼接。
- 候选边图同时保留正反方向；处理 OpenCV 对“只接触、不重叠”的凸多边形误报。
- 长边除两端对齐外，还会从其他实测边长推导少量内部偏移，因此支持扑克牌和现场随机 T 接缝。
- 同一张牌的花纹只负责在几何合法解之间消歧，不会替代矩形、重叠、孔洞和边界检查。
- `texture_enabled=true` 为自动模式：纯色自备片跳过纹理开销，检测到数字/花色后才启用扑克牌路径。
- 所有求解路径统一检查填充率、重叠、孔洞、四边最小覆盖率、轮廓凸性、四角最大误差和边界 P95/P99；已确认的固定 Figure-2 只把栅格连通与边界误差改按官方 20 mm 对应顶点容差验收。
- 调试图顶部的 `side=` 是四条矩形边中最差一条的覆盖率，默认必须不低于 `0.88`。

## 坐标约定

- `paper_mm`：A4 校正坐标，原点为取料半区左上角，`x` 向右、`y` 向下，单位 mm。
- 代码会根据分界线和碎片自动消除相机画面中的 90°/180°摆放差异。
- `rotation_cw_deg`：从当前碎片姿态转到目标姿态的纸面顺时针旋转量，范围
  `[-180, 180)`。
- `pickup_paper_mm`：当前吸取位置。
- `place_paper_mm`：碎片旋转后，同一个吸取点应移动到的目标位置。吸嘴不在质心时也已经
  完成 XY 旋转补偿。
- `frame_to_robot`：把去畸变后的固定相机画面像素映射到龙门/机械臂毫米坐标的 3×3
  单应矩阵。程序会在线复合每次检测到的 A4 位姿，所以纸张在标定后发生平移或 90°/180°
  旋转时，机构坐标仍会同步更新。

运动控制应优先使用 `pickup_robot_mm`、`place_robot_mm` 和
`rotation_robot_deg`，不要用原始图像像素直接控制机构。输出顶层
`robot_calibrated=false` 时，这三项仍只是未标定诊断值，禁止据此驱动机构。

当前 UART 协议在发送前按 `80 pulse/mm` 把内部机构毫米坐标转换为回零后的绝对脉冲：

```json
{
  "piece_id": 0,
  "pickup_x_pulse": 9600,
  "pickup_y_pulse": 7200,
  "place_x_pulse": 18000,
  "place_y_pulse": 12800,
  "rotation_deg": 30.0
}
```

X 正方向从左向右，范围 `0..24000 pulse`；Y 正方向从上向下，范围
`0..16700 pulse`。四个 XY 字段都是绝对目标位置，不是从当前位置开始的相对运动量。
越界命令会在 UART 发送前被拒绝。旋转轴脉冲当量尚未确定，因此仍发送相对旋转角度。
UART 字段 `rotation_deg` 使用 `[0,360)` 内的顺时针角，`0` 表示无需旋转。

## MaixCAM2 运行

1. 先在设备设置中安装与系统匹配的最新 Runtime。
2. 用 MaixVision 打开整个 `maixcam2_puzzle_vision` 文件夹，必须选择“运行项目”，不能只
   运行 `main.py`，否则子模块不会上传。
3. 把 `config.example.json` 复制为 `config.json`，再按设备修改。`expected_piece_count=0` 接受现场的 1–4 片；
   已知固定为四片时可设为 `4`，能更早发现漏分割。默认使用
   `"solver_mode": "auto"`：先尝试固定图 2 的 48 次模板指派，形状不匹配时自动进入
   通用枚举。只有明确只测题图固定切法时才使用 `"figure2"`。
   `"texture_enabled": true` 会自动区分纯色片和扑克牌：纯色片跳过纹理评分，
   只有检测到牌面印刷图案时才比较接缝纹理。首轮通用搜索默认最多运行
   `15000 ms`；失败或只得到 `SEARCH_LIMIT` 候选时，恢复轮使用剩余预算，两轮求解合计不超过
   `30000 ms`。节点上限同时有效。
4. 默认保持 `"start_mode": "touch"`：`START` 拍摄并求解一轮，结果会一直保留；
   `STOP` 停止并丢弃本轮结果，`RESET` 清除本轮结果并恢复预览。`"immediate"` 仅用于上电自动
   求解一次；`"func_key"` 只作为旧硬件兼容项保留，正常使用不再需要 FUNC 键。
5. 需要给运动主控发送结果时启用 UART。当前硬件使用左侧 2.54 mm 排针的
   `U2T/U2R`，对应 B0/B1 的 UART2、`/dev/ttyS2` 和 3.3 V 电平；
   TX/RX 交叉并共地。当前 `config.json` 已写入本机 A4 四角标定并启用 UART；
   更换相机位置、分辨率、工作平面或坐标原点后，必须重新标定并先关闭真实运动。
   只验证接线和主控解析时，先关闭电机驱动并运行
   `tools/uart_smoke_test.py`；它发送 `status=UART_TEST` 的固定 JSON，
   不需要伪造机构标定状态。
6. 通过 MaixVision“安装应用”离线部署，或在项目目录运行 `maixtool release`。
   若要求上电后只按一次测试键，还要在设备“设置 → 开机启动”中选择本应用。正式测试前
   关闭 Wi-Fi，并确认断开电脑后可以独立运行。

板载相机由 `maix.camera.Camera` 取帧，再由 `image.image2cv` 转成 OpenCV BGR 数组。
不要把板载 MIPI 摄像头改成 PC 写法 `cv2.VideoCapture(0)`。

启动后终端应先出现类似
`[vision] config solver=auto, texture=on, pieces=auto, limit=15000 ms/attempt, 30000 ms total`。
固定图 2 在“solving puzzle...”之后还应立即出现
`[vision] trying bounded Figure-2 template solver`；其他切法随后会提示模板不匹配并
自动切换到 `generic C1/C2 mating solver`。缺少这些行说明板上仍是旧文件；
请停止运行并重新“运行项目/安装应用”整个文件夹，不能只发送 `main.py`。

## 建议的纸张和相机条件

- A4 必须是无纹理、哑光、纯色纸；建议选与白色现场片和自备片均有明显色差的中深色。
- 承载平台也应与 A4 颜色形成明显边界，但不能加入图案、角点或定位标记。
- 完整四条 A4 边和分界线必须在画面内；相机尽量正对纸面，焦点锁在纸面。
- 当前默认以 `1280×720` 取帧、以 `3 px/mm` 校正为 `630×891`。
- 相机帧率使用 MaixCAM2 官方模式中的 `30 fps`。
- 分界线可以不是黑色；代码按相对纸面 Lab 色差寻找贯穿纸宽的中部线。
- 现场碎片可能同形异纹，因此扑克牌配置不要关闭纹理评分；若自备纯色片之间本来就允许
  颜色跳变，则应关闭，否则“颜色连续性”会成为错误先验。
- `assembly.search_complete=true` 才表示有限候选集已经搜索完；触及节点/候选上限会返回
  `SEARCH_LIMIT`，不会冒充唯一解。
- `assembly.side_coverage_min`、`convexity_ratio` 和 `corner_error_max_mm` 是严格矩形资格指标；
  默认分别要求 `>=0.88`、`>=0.96`、`<=5 mm`。不要只看 `fill_ratio`。
- `paper_border_exclusion_mm` 和 `divider_exclusion_mm` 只用于背景/阈值估计，不再把
  靠近纸边或中线的合法碎片直接判错；规则保证碎片本身仍完整位于取料半区。
- 两片同色碎片若无缝贴合，单幅顶视图可能与“一片完整碎片”完全相同，这是不可观测情况。
  已知片数的自备题务必配置准确片数并留出可见间隙；现场题若出现这种极端摆法，任何仅靠
  单帧轮廓的方案都不能保证恢复真实分界。

## 相机内参标定

先在非测评阶段用棋盘格从不同位置、角度拍摄至少 8 张图：

```powershell
python tools/calibrate_camera.py "calibration/*.jpg" `
  --columns 9 --rows 6 --square-mm 20
```

把生成结果中的 `camera_matrix` 和 `distortion_coefficients` 复制到 `config.json`。标定
照片必须和正式运行使用相同的 `1280×720` 分辨率。标定图仅用于赛前镜头标定，正式 A4
纸上仍不放任何标记。

## 固定相机到机构坐标标定

锁紧相机后，在工作平面记录至少四组（建议 8–12 组）去畸变画面像素和机构实测坐标。
标定点应覆盖整个 A4 工作范围：

先保存一张与正式运行分辨率、方向完全相同的原始相机图，然后在电脑上运行点选工具：

```powershell
python tools/collect_calibration_points.py calibration_frame.jpg `
  --config config.json `
  --output calibration_points.json
```

建议先给标定纸上的十字编号，并按编号顺序点选。在窗口中左键依次点击十字中心；右键、
退格键或 `Z` 撤销，至少点四个点后按
回车结束，`Esc` 取消。图片即使为了显示而缩小，工具也会自动换算回原图像素坐标。之后
按终端提示，为每个编号输入同一个物理点的机构 `Xmm Ymm`。

如果主控目前只有绝对脉冲位置，也可以让工具按脉冲当量换算毫米。例如 X/Y 分别为
80 和 100 pulse/mm，回零脉冲均为 0：

```powershell
python tools/collect_calibration_points.py calibration_frame.jpg `
  --config config.json `
  --x-pulses-per-mm 80 `
  --y-pulses-per-mm 100
```

轴正方向相反时追加 `--x-direction -1` 或 `--y-direction -1`；回零对应的计数不为零时使用
`--x-zero-pulse`、`--y-zero-pulse`。如果暂时只想取得像素坐标，可使用
`--pixels-only`，之后再手动补上数量和顺序完全一致的 `robot_mm`。

输入完成后会直接生成如下格式：

```json
{
  "frame_px": [[420, 80], [850, 90], [900, 680], [360, 670]],
  "robot_mm": [[...], [...], [...], [...]]
}
```

然后执行：

```powershell
python tools/fit_frame_to_robot.py calibration_points.json
```

把输出的 `frame_to_robot` 复制到 `config.json`，复测通过后才把
`robot_calibrated` 改成 `true`。建议用未参与拟合的点做复测，整张 A4 范围内误差应显著
小于机械系统允许误差。标定照片若启用了镜头内参矫正，像素点也必须取自矫正后的画面。
如果输入的是已经去畸变并保存的图片，点选工具不要再传 `--config`，避免重复去畸变。
程序会在“启用 UART 但未声明完成标定”时拒绝启动，防止把画面像素误当成机构毫米坐标。

## PC 端实拍回放

```powershell
python tools/run_image.py frame.jpg `
  --config config.json `
  --output debug_result.jpg `
  --json result.json
```

`debug_result.jpg` 同时显示源轮廓/吸取点和下半区目标轮廓/放置点。每次现场调参应保存原始
帧并离线回放，避免只根据屏幕预览改阈值。

## 自动测试

测试不需要真实相机，会生成图 2 的 10 cm×6 cm 四片拼图、随机源姿态、非白 A4、透视
畸变、非黑色分界线以及横向/倒置摆纸场景：

```powershell
python -m unittest tests.test_vision -v
```

当前 80 项测试检查：

- 图 2 中 `2+8 cm`、`2+1+3 cm` 以及斜边分段形成的 T 接缝；
- A4 四角、分界线、四片分割和毫米坐标；
- 目标矩形尺寸、填充率、重叠率和目标位姿；
- 横向、倒置 A4 后仍规范化为上取料、下拼图；
- 规则允许的 `90×120 mm` 单片最大矩形；
- 明暗渐变和轻度传感器噪声；
- 缺角五边形拒绝、非凸共边不误算重叠、搜索上限不冒充完整；
- 仅约 10% 接缝带花纹的同形矩形纹理消歧；
- 实拍扑克牌四片、重复/旋转/全四边形拍摄节点预算、切边印花假缺口修复、尖角近接时的四片分离、细内接缝不误算外边界、凸多边形零穿透共边、长边内部偏移和自动纯色/牌面分流；
- 非质心吸取旋转补偿、横放纸张的在线机构坐标复合及反射坐标系旋转符号；
- 靠纸边轮廓被裁切时安全拒绝；
- 输出 JSON 可序列化。

## 现场必须实测的参数

合成测试不能代替 MaixCAM2 实拍。拿到相机后至少采集：

- 自备纯色片 20 组随机位置和旋转；
- 现场同材质白片或自制镀锌薄铁片 20 组；
- 多张不同扑克牌、不同切法和同形异纹样本；
- 实验室不同灯位、曝光和轻微阴影；
- 上下半区不同阴影和分界线附近的亮暗带；
- 碎片靠近纸边、分界线，以及彼此间隔 `0.5–3 mm` 的边界情况。

记录分割片数、顶点毫米误差、拼接拓扑、旋转误差、运行时间和失败帧。若实际纸色、镜头、
安装高度或曝光改变，应先用这些回放帧调整 `config.json`，不要在求解器里散加特殊判断。

## 与运动主控的边界

本项目到 UART JSON 运动计划为止，是视觉协处理器代码，不包含电机闭环。运动主控还应：

1. 对整帧 JSON 做缓存后再解析，不能收到半包就动作；
2. 对每片执行吸取、旋转、放置并返回 ACK，失败时在两分钟内自动重试；
3. 全部执行后复核机构状态，再触发题目要求的声音或灯光提示。

`status=LOW_MARGIN`、`SEARCH_LIMIT` 或 `ERROR` 时板端不会通过 UART 下发动作列表。

## 官方接口参考

- MaixCAM2 快速开始：<https://wiki.sipeed.com/maixpy/doc/en/README_MaixCAM2.html>
- MaixPy 相机：<https://en.wiki.sipeed.com/maixpy/doc/en/vision/camera.html>
- MaixPy + OpenCV：<https://wiki.sipeed.com/maixpy/doc/en/vision/opencv.html>
- MaixPy 官方仓库：<https://github.com/sipeed/MaixPy>
- Maix 应用打包：<https://wiki.sipeed.com/maixpy/doc/zh/basic/app.html>

## 几何求解算法参考

- Harel 等人的 Crossing Cuts Polygonal Puzzles：C1 边长、C2 补角、配准图、闭环一致性和
  物理碎片直线矢量化：<https://openaccess.thecvf.com/content/CVPR2021/html/Harel_Crossing_Cuts_Polygonal_Puzzles_Models_and_Solvers_CVPR_2021_paper.html>
- Gur 等人的 From Square Pieces to Brick Walls：长边上任意平移位置的配准与跨缝图像相容性：
  <https://openaccess.thecvf.com/content_iccv_2017/html/Gur_From_Square_Pieces_ICCV_2017_paper.html>
- Gallagher 的未知朝向拼图 MGC 接缝相容性：
  <https://chenlab.ece.cornell.edu/people/Andy/Andy_files/Gallagher_cvpr2012_puzzleAssembly.pdf>
- OpenCV 轮廓近似、鲁棒直线拟合等官方接口：
  <https://docs.opencv.org/4.13.0/d3/dc0/group__imgproc__shape.html>

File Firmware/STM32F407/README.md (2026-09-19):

# STM32F407 Motion Controller

主控工程基于 STM32F407VGT6、STM32CubeMX 和 HAL 库，负责四轴运动、电磁铁吸放、限位与回零、OLED状态显示，以及接收 MaixCAM2 发来的 JSONL 运动计划。

## 打开与编译

1. 使用 STM32CubeMX 打开 `Automatic inspection vehicle.ioc` 查看外设配置。
2. 使用 Keil MDK-ARM 打开 `MDK-ARM/Automatic inspection vehicle.uvprojx`。
3. 编译并通过调试器烧录到 STM32F407VGT6。

## 主要目录

- `app/`：任务状态机和视觉串口协议解析。
- `hardware/`：四轴、电磁铁、限位、位置、OLED和底层驱动封装。
- `Core/`：CubeMX生成的初始化、中断和主程序代码。
- `Drivers/`：CMSIS与STM32F4 HAL库。
- `tests/`：主机端C测试和PowerShell策略检查。

烧录后先在断开负载或低速状态下逐轴验证方向、限位、回零和电磁铁，再连接视觉模块进行整机测试。

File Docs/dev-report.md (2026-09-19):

# 开发报告

| # | Date | Type | Description | Status | Resolution |
|---|---|---|---|---|---|
| 1 | 2026-09-19 | Feature | 将竞赛工程整理为 Puzzle-Device 开源仓库并发布到 GitHub | ✅ | 已完成目录整理、使用说明、演示入口、缓存与本机配置清理，并通过可用测试与仓库结构检查。 |

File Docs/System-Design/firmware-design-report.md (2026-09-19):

# 拼图装置设计报告

> 排版要求(在 Word 中设置):正文小四号宋体、行距固定值 22 磅、纵向打印;每页上方留 ≥3cm 空白且空白区内无文字;页码置于每页右下角;全文(含封面)不得出现学校、队代码、姓名,否则按作弊处理。正文严格控制在 A4 八页以内,摘要单独置于首页、300 字以内。
> 仅剩 4 个数字需要替换为实测值,见文末"待填清单"。

---

## 摘要(置首页,300 字以内)

本作品设计并制作了一台自动拼图装置。装置以 STM32F407 为主控,采用 X/Y/Z 三轴 Emm42 串口总线闭环步进平台与 R 轴舵机旋转的直角坐标结构,电磁铁吸取镀锌薄铁片碎片;MaixCAM2 视觉模块完成碎片识别、目标矩形解算与放置规划,经串口以 JSON 行协议下发脉冲域动作计划,主控逐片执行"移动—吸取—搬运—旋转—释放"。装置上电自动回零,一键启动后全自动拼图,完成后声光指示。实测装置可将 4 片白纸碎片正确拼合为目标矩形,对扑克牌牌面碎片亦能正确拼合且花纹对应一致,相邻碎片对应顶点距离与完成时间均满足题目要求。

关键词:拼图装置;闭环步进;电磁吸取;视觉识别;拼接算法

---

## 一、方案论证

### 1.1 总体方案

系统由直角坐标运动平台、末端执行器、视觉识别单元和主控单元四部分组成。测评时先遮挡摄像头,随机摆放碎片后一键启动并移除遮挡:MaixCAM2 采集上半区图像,识别各碎片的位置、姿态与轮廓,解算目标矩形并规划各碎片的目标位姿,将结果整理为脉冲域动作计划经 USART2 下发;主控校验计划后,驱动 X/Y/Z 步进与 R 轴舵机,配合电磁铁逐片完成搬运拼合,每片之间自动回零消除累积误差;全部完成后给出声光指示。

### 1.2 方案比较与选择

**运动机构**:方案一为串联机械臂,结构紧凑但逆运动学复杂、末端刚度低;方案二为直角坐标三轴平台加末端旋转轴,控制简单、定位精度高,与 A4 平面作业天然匹配。选择方案二。

**驱动电机**:方案一为开环脉冲步进,存在丢步风险,需外加限位与脉冲计数;方案二为 Emm42 串口总线闭环步进,支持位置/速度模式、绝对位置回读、驱动器内零点存储与 0x9A 一键回零,单线总线布线简洁。选择方案二(X 轴接 USART3,Y 轴接 USART6,Z 轴接 UART4,均 115200bps)。

**抓取方式**:现场碎片为镀锌薄铁片贴纸片。方案一真空吸盘需气源,体积与噪声大;方案二电磁铁吸取,响应快、结构简单,针对剩磁粘连增加 50ms 全占空反向退磁脉冲,释放可靠。选择方案二。

**识别方案**:方案一由主控直接处理图像,STM32 算力与存储不足;方案二由独立视觉模块 MaixCAM2 完成全部图像处理与拼接解算,主控只接收最终动作计划,分工清晰、开发解耦。选择方案二。

### 1.3 主控选择

STM32F407VET6,168MHz 主频,具备 6 路串口与多路定时器 PWM,可同时满足三轴串口步进、舵机、电磁铁、视觉串口、调试串口与 OLED 显示的资源需求。

## 二、理论分析与计算

### 2.1 脉冲-位移换算与坐标标定

步进电机单圈 3200 脉冲。X/Y 轴每毫米脉冲数经标定任务实测为 Kx=①、Ky=② 脉冲/mm。视觉端以画面中已知物理尺寸的参照(目标矩形/A4 纸边界)做像素-脉冲两点标定,将碎片像素坐标直接换算为脉冲坐标,标定状态随计划下发(robot_calibrated 标志),主控据此拒绝未标定的计划,保证量纲一致。

### 2.2 碎片识别

白纸碎片与底色对比明显:MaixCAM2 对图像做颜色阈值分割获得碎片连通域,经轮廓提取与多边形逼近得到各碎片顶点;对轮廓做最小外接矩形求得中心位置与主轴姿态角。扑克牌牌面碎片在几何识别基础上,对牌面图案做模板匹配,确定碎片在整牌中的归属与朝向,从而同时满足位置正确与花纹对应两项要求。识别结果(碎片中心、姿态)经 2.1 的标定换算为脉冲坐标。

### 2.3 拼接算法

利用题目约束"每片至少有 1 条边位于目标矩形外边":对识别出的各碎片边长按降序与目标矩形四条外边及其他碎片边做匹配,确定每片在目标矩形中的角/边归属;再由碎片顶点几何关系解算其目标中心与旋转角,生成 {碎片编号, 吸取坐标, 放置坐标, 旋转角} 的动作计划。放置顺序按"先大后小、互不遮挡"排序,避免后放碎片碰移先放碎片。视觉端将 1~4 片的完整计划一次性下发,主控整包校验(编号唯一、坐标与角度范围合法)后才执行,杜绝半包、错包造成的误动作。

### 2.4 精度分析

相邻碎片对应顶点误差的主要来源:视觉标定误差、机械传动间隙、释放瞬间偏移。应对措施:视觉端两点标定将像素误差限制在亚毫米级;每片放置完成后三轴自动回驱动器零点(0x9A 回零+0x3B 状态确认),消除开环累积误差;电磁铁 50ms 反向退磁使释放无拖拽。实测相邻碎片对应顶点距离最大值为 ③ cm,优于 2cm 的指标要求。

## 三、电路与程序设计

### 3.1 电路设计

- 主控最小系统:STM32F407VET6,8MHz HSE 经 PLL 至 168MHz。
- 电机驱动:X/Y/Z 三台 Emm42 闭环步进驱动器分别接 USART3(PD8/PD9)、USART6(PC6/PC7)、UART4(PA0/PC11),地址均设为 1,115200bps,共地连接。
- 末端执行器:R 轴 180° 舵机由 TIM1_CH4(PE14)驱动,50Hz、500–2500µs 脉宽;电磁铁经 H 桥驱动,TIM1_CH3(PE13)PWM 调压、PC2/PC3 换向,支持吸合/反向退磁/关断三态。
- 人机交互:SSD1306 OLED(I2C1,PB6/PB7)显示任务与状态;4 个轻触按键(PB12–PB15,EXTI 下降沿+30ms 防抖)实现切换/启动暂停/退出/复位;完成指示 LED(PB1)与蜂鸣器(PB2)。
- 通讯接口:USART2(PA2/PA3)接 MaixCAM2,接收 JSON 行计划;USART1(PA9/PA10)为调试与上位机口,指令经软件桥接共用解析通道,便于联调。

### 3.2 程序设计

软件采用裸机轮询架构,中断只做最小化处理(按键沿记录、串口字节接收、1ms 系统节拍),主循环依次执行按键分发、运动处理、任务状态机与显示刷新。程序分三层:

**驱动层**:Emm42 协议组包/解析(使能 0xF3、位置 0xFD、速度 0xF6、停止 0xFE、回零 0x9A、回零状态 0x3B、设零点 0x93、读位置 0x36)、舵机 PWM、电磁铁 H 桥、OLED、按键消抖。

**运动层**:四轴统一串口抽象,支持角度/脉冲两种相对运动、基于时间预算与位置回读的完成判定、暂停/恢复/中止、单轴标定、软件行程限位(X≤29500、Y≤16800、Z≤300 脉冲)以及上电初始化。任务1摄像头字段按同名轴映射:摄像头X(0..24000)→机械X(0..29500),摄像头Y(0..16700)→机械Y(0..16800)。

**任务层**:任务状态机(空闲/运行/暂停/完成/错误)管理 9 个任务,脚本式动作队列支持"轴运动+电磁铁"混合编排;视觉 JSON 行协议(UART-JSONL-PULSE-v1)整包解析校验后,逐片执行搬运、放置前按 rotation_deg 旋转 R 轴,片间自动回零;任何任务完成后 LED 保持点亮、蜂鸣器鸣响 0.5s。

主程序流程:上电初始化→三轴使能并回零→待机→按键选择任务→(任务 1/9)等待视觉计划→校验→逐片执行→声光提示→待机。

## 四、测试方案与测试结果

### 4.1 测试方案

仪器:秒表、直尺。方法:按测评规程遮挡摄像头、随机不重叠摆放碎片,一键启动同时移除遮挡并计时;完成后用直尺测量相邻碎片对应顶点距离,检查碎片位置、重叠情况与牌面花纹对应,记录完成时间;多次重复取最差值。

### 4.2 测试结果

| 测试项 | 指标 | 实测结果 | 结论 |
|---|---|---|---|
| 4 片碎片全部移至下半区 | 全部 | 4/4 | 达标 |
| 白纸碎片拼合 | 位置正确、不重叠、顶点距≤2cm | 拼合成正确矩形,顶点距最大 ③ cm | 达标 |
| 白纸碎片完成时间 | ≤2min | ④ s | 达标 |
| 扑克牌碎片拼合 | 位置正确、花纹对应 | 花纹对应正确 | 达标 |
| 扑克牌完成时间 | ≤2min,越短越好 | ⑤ s | 达标 |
| 一键启动、中途无干预、声光指示 | 具备 | 具备 | 达标 |

结果分析:装置对白纸碎片与扑克牌碎片均能稳定完成拼合。误差主要来自视觉标定残差与释放偏移,通过片间回零与退磁释放得到有效抑制,顶点距离指标留有充分裕量。

## 五、结论

本装置完成了题目要求的全部功能:碎片自动识别、搬运与拼合,白纸碎片与扑克牌碎片均实测成功,拼合精度与用时满足指标。不足与改进方向:视觉标定依赖一次性两点标定,可升级为多点标定进一步提高精度;放置策略可引入闭环复拍修正,进一步压缩顶点间距。

## 参考文献

[1] Emm_V5 步进闭环驱动器串口通讯协议说明书
[2] STM32F4xx 参考手册(RM0090)
[3] MaixCAM2 视觉模块开发文档

---

## 待填清单(替换后删除本节)

- ① Kx(X 轴每毫米脉冲数,标定任务 4 实测)
- ② Ky(Y 轴每毫米脉冲数,标定任务 5 实测)
- ③ 相邻碎片对应顶点距离最大值(cm,多次实测最差值)
- ④ 白纸碎片拼合总时间(s)
- ⑤ 扑克牌碎片拼合总时间(s)

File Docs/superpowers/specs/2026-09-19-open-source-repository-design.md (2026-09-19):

# Puzzle Device 开源仓库设计

## 目标

将现有 STM32 控制工程、MaixCAM2 视觉程序、嘉立创 EDA 工程和 3D 打印文件整理成可阅读、可下载、可复现的公开仓库，并提供清晰的使用路径和演示入口。

## 目录设计

- `Firmware/STM32F407/`：STM32CubeMX/HAL 四轴运动控制、通信和执行机构程序。
- `Firmware/MaixCAM2-Vision/`：视觉检测、几何解算、拼图求解、配置示例和测试。
- `Hardware/Schematic/`、`Hardware/PCB/`、`Hardware/BOM/`：硬件工程文件及缺失资料说明。
- `Mechanical/STL/`、`Mechanical/STEP/`：3D 打印模型及缺失资料说明。
- `Docs/System-Design/`：系统设计和开发资料。
- `Docs/Images/`：README 可引用的项目图片。
- `Demo/`：演示说明与 Bilibili 视频入口。

## 发布策略

源码直接纳入 Git；排除嵌套 `.git`、编译输出、缓存、临时文件、历史发布包和本机配置。原始压缩包保留在仓库目录之外，不上传 GitHub。仓库采用已有 MIT License。

## 验收条件

目录完整；README 包含项目原理、结构、准备、烧录、部署、运行和演示链接；不存在超过 GitHub 单文件限制的文件；不存在明显的本机密钥或敏感配置；Git 工作树干净并成功推送到 `main`。

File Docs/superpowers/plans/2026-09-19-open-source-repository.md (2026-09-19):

# Puzzle Device Open-Source Repository Implementation Plan

> **For agentic workers:** REQUIRED SUB-SKILL: Use superpowers:executing-plans to implement this plan task-by-task. Steps use checkbox (`- [ ]`) syntax for tracking.

**Goal:** 将竞赛工程整理为可阅读、可复现并能直接发布到 GitHub 的开源仓库。

**Architecture:** 保留固件、硬件、机械、文档和演示五个清晰边界；源码直接纳入 Git，生成物和本机配置通过清理与 `.gitignore` 排除。根 README 负责项目介绍和完整使用路径，各子目录 README 说明该目录内容及工具要求。

**Tech Stack:** STM32CubeMX/HAL、MaixCAM2/Python、嘉立创EDA、STL、Git/GitHub。

---

### Task 1: 整理源码与设计资料

**Files:**
- Create: `Firmware/STM32F407/`
- Create: `Firmware/MaixCAM2-Vision/`
- Create: `Hardware/Schematic/`
- Create: `Hardware/PCB/README.md`
- Create: `Hardware/BOM/README.md`
- Create: `Mechanical/STL/`
- Create: `Mechanical/STEP/README.md`
- Create: `Docs/System-Design/`

- [x] 解压 STM32 工程，排除嵌套 `.git` 和编译输出，并复制到 `Firmware/STM32F407/`。
- [x] 解压 MaixCAM2 工程，删除缓存、临时目录、历史发布包和 `config.json`，保留 `config.example.json`。
- [x] 复制 EDA 工程、STL 文件和系统设计资料到对应目录。
- [x] 检查目录中不存在 `.git`、`__pycache__`、`.pytest_cache`、构建缓存和超过 100 MB 的文件。

### Task 2: 编写开源说明

**Files:**
- Modify: `README.md`
- Create: `.gitignore`
- Create: `Firmware/README.md`
- Create: `Hardware/README.md`
- Create: `Mechanical/README.md`
- Create: `Docs/README.md`
- Create: `Demo/README.md`

- [x] 编写项目概述、功能、系统流程、目录树和技术组成。
- [x] 编写 STM32 烧录、MaixCAM2 配置部署、接线检查、上电初始化和一键启动步骤。
- [x] 在 `Demo/README.md` 和根 README 中加入 Bilibili 演示入口。
- [x] 标注当前未提供的 PCB Gerber、BOM 和 STEP 文件，避免读者误判。

### Task 3: 验证与发布

**Files:**
- Modify: `Docs/dev-log.md`
- Modify: `Docs/dev-report.md`

- [x] 扫描敏感信息、绝对路径、缓存、嵌套仓库和超大文件。
- [x] 运行视觉模块测试；若依赖环境不满足，记录可复现的失败原因。
- [x] 检查 README 中的相对链接和目录引用均存在。
- [x] 更新开发日志，提交全部文件并推送 `main`。
- [x] 通过 GitHub API核对远程提交、README、许可证及主要目录。

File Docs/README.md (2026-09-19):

# Docs

- `System-Design/`：系统设计与固件实现说明。
- `Images/`：用于保存装置外观、接线和运行效果图片。
- `superpowers/`：本次开源整理的设计与实施记录。
- `dev-log.md`、`dev-report.md`：仓库整理过程记录。

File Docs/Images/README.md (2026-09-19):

# Images

项目图片预留目录。提交图片时建议使用压缩后的 JPG/WebP，并在根 README 中添加说明和替代文本。

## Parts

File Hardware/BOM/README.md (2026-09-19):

# BOM

当前开源包尚未整理正式 BOM。复现者应根据嘉立创EDA工程和实际机构选型确认 STM32F407 主控、步进驱动器、电机、电磁铁、限位器件、MaixCAM2、供电及连接器规格。

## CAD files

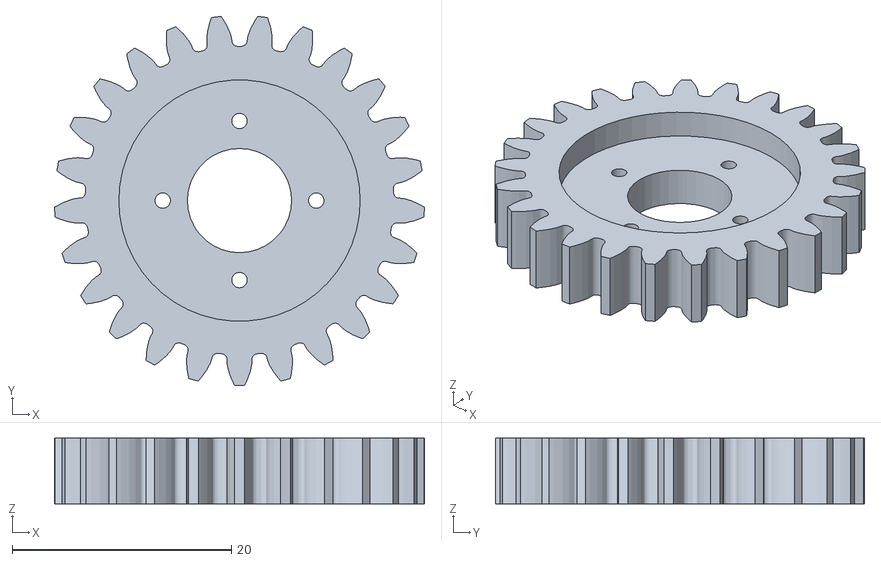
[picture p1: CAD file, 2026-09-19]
Mechanical/STL/圆柱齿轮25×1.25.STL
33.7 x 33.7 x 6.00

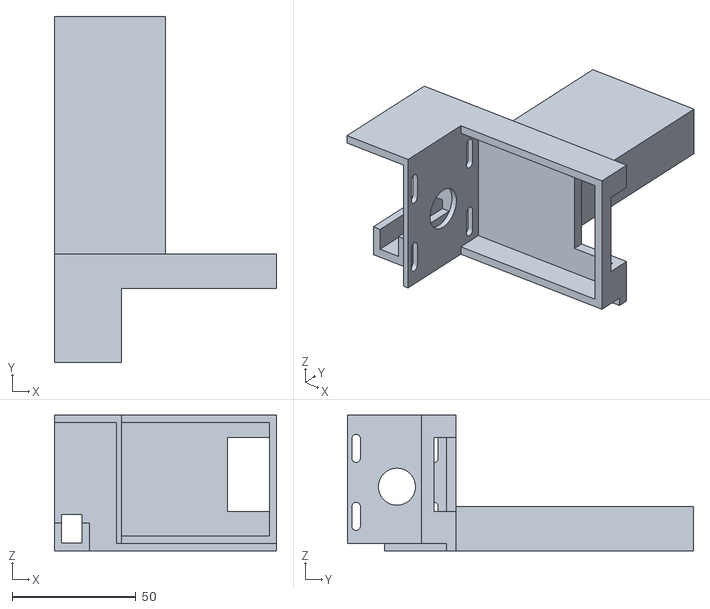
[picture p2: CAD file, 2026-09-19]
Mechanical/STL/束缚装置.STL
90.0 x 140.0 x 55.0

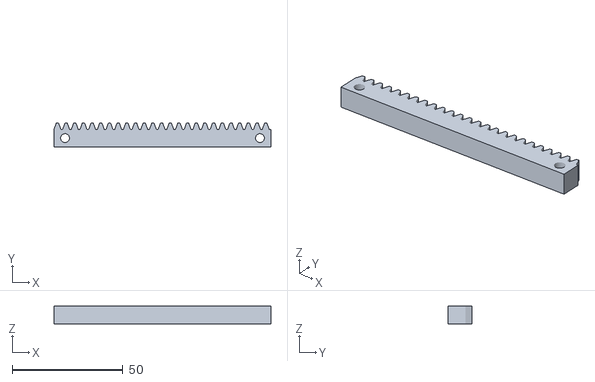
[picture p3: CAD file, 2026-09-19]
Mechanical/STL/齿条0.098174770424681×1.25.STL
98.2 x 10.8 x 8.00

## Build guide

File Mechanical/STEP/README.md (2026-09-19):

# STEP

当前开源包尚未包含 STEP 装配模型。已有可打印模型位于 `../STL/`。

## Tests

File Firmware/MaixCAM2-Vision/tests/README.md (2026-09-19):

# Vision tests

`test_calibration_points.py` 和多数合成场景测试可直接运行。部分 `test_vision.py` 回归用例引用比赛期间采集的实拍图片，以及设备本机生成的 `config.json`；这些文件没有包含在当前开源包中，因此完整运行时会显示缺文件错误。

可直接运行的基础测试：

```powershell
python -m unittest tests.test_calibration_points -v
```

运行完整测试集：

```powershell
python -m unittest tests.test_vision -v
```

若要恢复全部实拍回归测试，请把对应图片放入 `tests/data/`，并由 `config.example.json` 生成经过本机标定的 `config.json`。不要提交包含真实机构标定参数的本机配置。

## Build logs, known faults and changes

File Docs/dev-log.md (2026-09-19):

# 开发日志

## 开发周期 1 | 2026-09-19 · 开源仓库整理 ✅

> Agent：Codex  
> 模型：GPT-5

| # | 任务 | 文件 | 具体改动 |
|---|---|---|---|
| 1 | 仓库结构设计 | `Docs/superpowers/specs/2026-09-19-open-source-repository-design.md` | 规划固件、硬件、机械、文档和演示目录，定义发布排除项与验收条件。 |
| 2 | 工程资料整理 | `Firmware/`、`Hardware/`、`Mechanical/` | 归类STM32与MaixCAM2源码、嘉立创EDA工程和STL文件，排除缓存、构建产物、本机配置和历史发布包。 |
| 3 | 开源使用说明 | `README.md`、各模块 `README.md`、`Demo/README.md` | 补充系统原理、目录、烧录、部署、标定、联调、操作流程和Bilibili演示入口。 |
| 4 | 验证 | 全仓库 | STM32策略脚本29/29通过；视觉基础标定测试3/3通过；完整视觉测试74项通过、14项因未发布的实拍图片和本机配置缺失而报错，已在测试说明中记录。 |

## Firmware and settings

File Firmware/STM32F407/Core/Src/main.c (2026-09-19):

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
/* Includes ------------------------------------------------------------------*/
#include "main.h"
#include "dma.h"
#include "i2c.h"
#include "tim.h"
#include "usart.h"
#include "gpio.h"

/* USER CODE BEGIN Includes */
#include "oled.h"
#include "key_input.h"
#include "four_axis.h"
#include "status_ui.h"
#include "electromagnet.h"
#include "task.h"
#include "vision_jsonl.h"
#include "debug_uart.h"
#include "dma_rx_cursor.h"
#include "stdio.h"
#include "string.h"
/* USER CODE END Includes */

/* USER CODE BEGIN PD */
#define KEY_PIN_TO_ID(pin) \
    ((pin) == key1_Pin ? KEY1_PIN_ID : \
    ((pin) == key2_Pin ? KEY2_PIN_ID : \
    ((pin) == key3_Pin ? KEY3_PIN_ID : KEY4_PIN_ID)))
/* USER CODE END PD */


/* USER CODE BEGIN PV */
static uint8_t vofa_rx_byte;
static char vision_rx_log[1024];
static char host_rx_log[256];
static volatile uint16_t host_rx_size;
static volatile uint8_t host_rx_ready;
#define USART2_DMA_RX_SIZE 1024u
static uint8_t usart2_dma_rx[USART2_DMA_RX_SIZE];
static DmaRxCursor_t usart2_cursor;
static volatile uint16_t usart2_dma_producer;
static volatile uint8_t usart2_dma_event_pending;
static volatile uint8_t usart2_recovery_pending;
static volatile uint32_t usart2_pending_error;
static uint32_t usart2_recovery_count;
static uint32_t usart2_last_byte_tick;
static uint16_t usart2_partial_bytes;
static uint8_t usart2_partial_reported;
static uint8_t task1_auto_started;
/* USER CODE END PV */

void SystemClock_Config(void);
/* USER CODE BEGIN 0 */

/* printf 重定向到 USART1（DAPLink 虚拟串口），防止 semihosting 导致卡死 */
#ifdef __GNUC__
  #define PUTCHAR_PROTOTYPE int __io_putchar(int ch)
#else
  #define PUTCHAR_PROTOTYPE int fputc(int ch, FILE *f)
#endif

PUTCHAR_PROTOTYPE
{
    DebugUart_PutChar(ch);
    return ch;
}

static void Task_SetElectromagnets(uint8_t mode, uint16_t duty_permyriad)
{
    Electromagnet_Set(0u, (ElectromagnetMode_t)mode, duty_permyriad);
}

static uint8_t Task_HomingProcess(void)
{
    return (uint8_t)FourAxis_HomingProcess();
}

static uint8_t Task_RecordedHomeProcess(void)
{
    return (uint8_t)FourAxis_RecordedHomeProcess();
}

static void Task_SendResponse(const char *text)
{
    /* USART1 is the interactive host port. USART2 is receive-only JSONL. */
    DebugUart_Printf("%s\r\n", text);
}

static void Task_SetBeeper(uint8_t on)
{
    /* PB0 = buzzer, active high. */
    HAL_GPIO_WritePin(GPIOB, GPIO_PIN_0, on ? GPIO_PIN_SET : GPIO_PIN_RESET);
}

static void Task_SetLight(uint8_t on)
{
    HAL_GPIO_WritePin(light_GPIO_Port, light_Pin, on ? GPIO_PIN_SET : GPIO_PIN_RESET);
}

static const TaskMotionOps_t task_motion_ops = {
    FourAxis_StartAll360,
    FourAxis_PauseAll,
    FourAxis_ResumeAll,
    FourAxis_AbortAll,
    FourAxis_GetProgress,
    FourAxis_AllComplete,
    Task_SetElectromagnets,
    FourAxis_StartMove,
    FourAxis_MoveComplete,
    FourAxis_MoveFailed,
    HAL_GetTick,
    FourAxis_StartCalibration,
    FourAxis_PauseCalibration,
    FourAxis_ResumeCalibration,
    FourAxis_StopCalibration,
    FourAxis_GetCalibrationPulses,
    FourAxis_StartMovePulses,
    FourAxis_StartMovePulsesAtSpeed,
    FourAxis_HomingStart,
    Task_HomingProcess,
    Task_SendResponse,
    Task_SetBeeper,
    Task_SetLight,
    FourAxis_SetHomingZeroAll,
    FourAxis_CaptureHomeReference,
    FourAxis_RecordedHomeStart,
    Task_RecordedHomeProcess,
    FourAxis_SetTask1OpenLoop
};

static void USART2_StartDmaRx(void)
{
    if (HAL_UARTEx_ReceiveToIdle_DMA(&huart2, usart2_dma_rx,
                                     sizeof(usart2_dma_rx)) == HAL_OK)
        __HAL_DMA_DISABLE_IT(huart2.hdmarx, DMA_IT_HT);
}

static void USART2_ProcessDma(void)
{
    DmaRxSpan_t spans[2];
    uint16_t producer;
    uint8_t count;
    uint8_t span;
    uint32_t primask;
    if (usart2_recovery_pending)
    {
        uint32_t error;
        primask = __get_PRIMASK();
        __disable_irq();
        error = usart2_pending_error;
        usart2_recovery_pending = 0u;
        usart2_dma_event_pending = 0u;
        if (primask == 0u) __enable_irq();
        (void)HAL_UART_AbortReceive(&huart2);
        DmaRxCursor_Reset(&usart2_cursor);
        usart2_dma_producer = 0u;
        USART2_StartDmaRx();
        ++usart2_recovery_count;
        DebugUart_Printf("[USART2 ERROR] code=%08lX RECOVER=%lu\r\n",
                         (unsigned long)error,
                         (unsigned long)usart2_recovery_count);
    }
    if (usart2_dma_event_pending)
    {
        primask = __get_PRIMASK();
        __disable_irq();
        producer = usart2_dma_producer;
        usart2_dma_event_pending = 0u;
        if (primask == 0u) __enable_irq();
        count = DmaRxCursor_Update(&usart2_cursor, producer, spans);
        for (span = 0u; span < count; ++span)
        {
            uint16_t i;
            for (i = 0u; i < spans[span].size; ++i)
            {
                uint8_t byte = usart2_dma_rx[spans[span].offset + i];
                VisionJsonl_RxByte(byte);
                usart2_last_byte_tick = HAL_GetTick();
                if (byte == '\n')
                {
                    usart2_partial_bytes = 0u;
                    usart2_partial_reported = 0u;
                }
                else if (usart2_partial_bytes < 0xFFFFu)
                    ++usart2_partial_bytes;
            }
        }
    }
    if ((usart2_partial_bytes != 0u) && !usart2_partial_reported &&
        ((uint32_t)(HAL_GetTick() - usart2_last_byte_tick) >= 500u))
    {
        DebugUart_Printf("[USART2 PARTIAL] bytes=%u NO NEWLINE\r\n",
                         usart2_partial_bytes);
        usart2_partial_reported = 1u;
    }
}

/* USER CODE END 0 */

/**
  * @brief  The application entry point.
  * @retval int
  */
int main(void)
{

  /* MCU Configuration--------------------------------------------------------*/

  /* Reset of all peripherals, Initializes the Flash interface and the Systick. */
  HAL_Init();

  /* Configure the system clock */
  SystemClock_Config();

  /* Initialize all configured peripherals */
  MX_GPIO_Init();
  MX_DMA_Init();
  MX_I2C1_Init();
  MX_I2C2_Init();
  MX_TIM1_Init();
  MX_TIM2_Init();
  MX_TIM3_Init();
  MX_TIM4_Init();
  MX_USART1_UART_Init();
  MX_USART2_UART_Init();
  MX_USART3_UART_Init();
  MX_USART6_UART_Init();
  MX_I2C3_Init();
  MX_TIM10_Init();
  MX_TIM11_Init();
  MX_UART4_Init();
  MX_UART5_Init();
  /* USER CODE BEGIN 2 */
  DebugUart_Init();
  KeyInput_Init();
  FourAxis_Init();
  Electromagnet_HardwareInit();
  Task_Init(&task_motion_ops);
  VisionJsonl_Init();
  DmaRxCursor_Init(&usart2_cursor, sizeof(usart2_dma_rx));
  StatusUi_Init();
  USART2_StartDmaRx();
  HAL_UART_Receive_IT(&huart1, &vofa_rx_byte, 1u);
  /* USER CODE END 2 */

  /* Infinite loop */
  /* USER CODE BEGIN WHILE */
  while (1)
  {
    /* USER CODE END WHILE */

    /* USER CODE BEGIN 3 */
    uint32_t key_tick = HAL_GetTick();
    USART2_ProcessDma();
    if (host_rx_ready)
    {
      char host_line[sizeof(host_rx_log)];
      uint32_t primask = __get_PRIMASK();
      __disable_irq();
      strcpy(host_line, host_rx_log);
      host_rx_ready = 0u;
      host_rx_size = 0u;
      if (primask == 0u) __enable_irq();
      DebugUart_LogTextRx("USART1", "HOST", host_line);
    }
    FourAxisHomingState_t homing;
    KeyInput_UpdateLevel(KEY1_PIN_ID,
      HAL_GPIO_ReadPin(key1_GPIO_Port, key1_Pin) == GPIO_PIN_RESET, key_tick);
    KeyInput_UpdateLevel(KEY2_PIN_ID,
      HAL_GPIO_ReadPin(key2_GPIO_Port, key2_Pin) == GPIO_PIN_RESET, key_tick);
    KeyInput_UpdateLevel(KEY3_PIN_ID,
      HAL_GPIO_ReadPin(key3_GPIO_Port, key3_Pin) == GPIO_PIN_RESET, key_tick);
    KeyInput_UpdateLevel(KEY4_PIN_ID,
      HAL_GPIO_ReadPin(key4_GPIO_Port, key4_Pin) == GPIO_PIN_RESET, key_tick);
    KeyEvent_t event = KeyInput_TakeEvent();

    if (event == KEY_EVENT_RESET)
    {
      StatusUi_LogKey("RESET");
      NVIC_SystemReset();
    }
    FourAxis_Process();
    homing = FourAxis_GetHomingState();
    if (FourAxis_GetStartupState() == FOUR_AXIS_STARTUP_READY)
    {
      if (!task1_auto_started)
      {
        Task_AutoStartTask1();
        task1_auto_started = 1u;
      }
      VisionPlan_t vision_plan;
      char vision_status[32];
      VisionJsonlResult_t vision_result =
        VisionJsonl_ProcessWithRaw(&vision_plan, vision_status,
                                   sizeof(vision_status), vision_rx_log,
                                   sizeof(vision_rx_log));
      if (vision_result != VISION_JSONL_NONE)
        StatusUi_ShowTransient("UART2 RX");
      if (vision_result != VISION_JSONL_NONE)
        DebugUart_LogTextRx("USART2", "CAM", vision_rx_log);
      if (vision_result == VISION_JSONL_PLAN)
      {
        if (Task_SubmitVisionPlan(&vision_plan))
        {
          StatusUi_ShowTransient("JSON ACCEPT");
          printf("[JSONL] ACCEPT count=%u elapsed=%lu\r\n",
                 vision_plan.count, (unsigned long)vision_plan.elapsed_ms);
        }
        else
        {
          StatusUi_ShowTransient("TASK BUSY");
          printf("[JSONL] REJECT MACHINE BUSY/NOT TASK1\r\n");
        }
      }
      else if (vision_result == VISION_JSONL_REPORT)
      {
        StatusUi_ShowTransient("UART2 REPORT");
        printf("[JSONL] REPORT status=%s NO MOTION\r\n", vision_status);
      }
      else if (vision_result == VISION_JSONL_REJECT)
      {
        StatusUi_ShowTransient("JSON INVALID");
        printf("[JSONL] REJECT INVALID PLAN\r\n");
      }
      if (event == KEY_EVENT_NEXT)
      {
        StatusUi_LogKey("NEXT");
        Task_SelectNext();
      }
      else if (event == KEY_EVENT_TOGGLE)
      {
        StatusUi_LogKey("START/PAUSE");
        Task_StartOrTogglePause();
      }
      else if (event == KEY_EVENT_EXIT)
      {
        StatusUi_LogKey("EXIT");
        Task_Exit();
      }
      Task_Process();
    }
    StatusUi_Process(homing);
		
  }
  /* USER CODE END 3 */
}

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
/* USER CODE BEGIN 4 */

void HAL_GPIO_EXTI_Callback(uint16_t GPIO_Pin)
{
  if ((GPIO_Pin == key1_Pin) || (GPIO_Pin == key2_Pin) ||
      (GPIO_Pin == key3_Pin) || (GPIO_Pin == key4_Pin))
  {
    KeyInput_RecordIsr(KEY_PIN_TO_ID(GPIO_Pin), HAL_GetTick());
  }
}

void HAL_UART_RxCpltCallback(UART_HandleTypeDef *huart)
{
  if (huart->Instance == USART1)
  {
    /* VOFA bridge: USART1 command bytes enter the same line parser. */
    Task_CameraRxByte(vofa_rx_byte);
    if (!host_rx_ready)
    {
      if ((vofa_rx_byte == '\n') || (vofa_rx_byte == '\r'))
      {
        if (host_rx_size != 0u)
        {
          host_rx_log[host_rx_size] = '\0';
          host_rx_ready = 1u;
        }
      }
      else if (host_rx_size < (sizeof(host_rx_log) - 1u))
      {
        host_rx_log[host_rx_size++] = (char)vofa_rx_byte;
      }
      else host_rx_size = 0u;
    }
    HAL_UART_Receive_IT(&huart1, &vofa_rx_byte, 1u);
  }
}

void HAL_UARTEx_RxEventCallback(UART_HandleTypeDef *huart, uint16_t Size)
{
  if (huart->Instance == USART2)
  {
    usart2_dma_producer = Size;
    usart2_dma_event_pending = 1u;
  }
}

void HAL_UART_ErrorCallback(UART_HandleTypeDef *huart)
{
  if (huart->Instance == USART2)
  {
    usart2_pending_error = huart->ErrorCode;
    usart2_recovery_pending = 1u;
  }
}

void HAL_UART_TxCpltCallback(UART_HandleTypeDef *huart)
{
  DebugUart_TxComplete(huart);
}

/* USER CODE END 4 */
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


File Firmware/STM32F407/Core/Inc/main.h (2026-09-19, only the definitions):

#define M1_low_Pin GPIO_PIN_2
#define M1_low_GPIO_Port GPIOC
#define M1_high_Pin GPIO_PIN_3
#define M1_high_GPIO_Port GPIOC
#define M1_encoder_b_Pin GPIO_PIN_1
#define M1_encoder_b_GPIO_Port GPIOA
#define m0_tx_Pin GPIO_PIN_2
#define m0_tx_GPIO_Port GPIOA
#define m0_rx_Pin GPIO_PIN_3
#define m0_rx_GPIO_Port GPIOA
#define M2_low_Pin GPIO_PIN_4
#define M2_low_GPIO_Port GPIOA
#define M2_high_Pin GPIO_PIN_5
#define M2_high_GPIO_Port GPIOA
#define M2_encoder_a_Pin GPIO_PIN_6
#define M2_encoder_a_GPIO_Port GPIOA
#define M2_encoder_b_Pin GPIO_PIN_7
#define M2_encoder_b_GPIO_Port GPIOA
#define beep_Pin GPIO_PIN_0
#define beep_GPIO_Port GPIOB
#define light_Pin GPIO_PIN_1
#define light_GPIO_Port GPIOB
#define M1_left_Pin GPIO_PIN_13
#define M1_left_GPIO_Port GPIOE
#define M2_right_Pin GPIO_PIN_14
#define M2_right_GPIO_Port GPIOE
#define jg_scl_Pin GPIO_PIN_10
#define jg_scl_GPIO_Port GPIOB
#define jg_sda_Pin GPIO_PIN_11
#define jg_sda_GPIO_Port GPIOB
#define key1_Pin GPIO_PIN_12
#define key1_GPIO_Port GPIOB
#define key1_EXTI_IRQn EXTI15_10_IRQn
#define key2_Pin GPIO_PIN_13
#define key2_GPIO_Port GPIOB
#define key2_EXTI_IRQn EXTI15_10_IRQn
#define key3_Pin GPIO_PIN_14
#define key3_GPIO_Port GPIOB
#define key3_EXTI_IRQn EXTI15_10_IRQn
#define key4_Pin GPIO_PIN_15
#define key4_GPIO_Port GPIOB
#define key4_EXTI_IRQn EXTI15_10_IRQn
#define x_tx_Pin GPIO_PIN_8
#define x_tx_GPIO_Port GPIOD
#define x_rx_Pin GPIO_PIN_9
#define x_rx_GPIO_Port GPIOD
#define y_tx_Pin GPIO_PIN_6
#define y_tx_GPIO_Port GPIOC
#define y_rx_Pin GPIO_PIN_7
#define y_rx_GPIO_Port GPIOC
#define imu_sda_Pin GPIO_PIN_9
#define imu_sda_GPIO_Port GPIOC
#define imu_scl_Pin GPIO_PIN_8
#define imu_scl_GPIO_Port GPIOA
#define DAP_tx_Pin GPIO_PIN_9
#define DAP_tx_GPIO_Port GPIOA
#define DAP_rx_Pin GPIO_PIN_10
#define DAP_rx_GPIO_Port GPIOA
#define M1_encoder_a_Pin GPIO_PIN_15
#define M1_encoder_a_GPIO_Port GPIOA
#define x_dir_Pin GPIO_PIN_10
#define x_dir_GPIO_Port GPIOC
#define g1_Pin GPIO_PIN_0
#define g1_GPIO_Port GPIOD
#define g2_Pin GPIO_PIN_1
#define g2_GPIO_Port GPIOD
#define g5_Pin GPIO_PIN_4
#define g5_GPIO_Port GPIOD
#define g6_Pin GPIO_PIN_5
#define g6_GPIO_Port GPIOD
#define g7_Pin GPIO_PIN_6
#define g7_GPIO_Port GPIOD
#define g8_Pin GPIO_PIN_7
#define g8_GPIO_Port GPIOD
#define oled_scl_Pin GPIO_PIN_6
#define oled_scl_GPIO_Port GPIOB
#define oled_sda_Pin GPIO_PIN_7
#define oled_sda_GPIO_Port GPIOB
#define x_stp_Pin GPIO_PIN_8
#define x_stp_GPIO_Port GPIOB
#define y_stp_Pin GPIO_PIN_9
#define y_stp_GPIO_Port GPIOB
#define x_en_Pin GPIO_PIN_0
#define x_en_GPIO_Port GPIOE
#define y_en_Pin GPIO_PIN_1
#define y_en_GPIO_Port GPIOE

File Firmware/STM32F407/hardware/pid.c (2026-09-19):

#include <math.h>
#include "pid.h"
#include "stdint.h"
#include <stddef.h>
#define PID_LIMIT_MIN -800     //PID输出最低值
#define PID_LIMIT_MAX 800 //PID输出最大值
//注意：PID结构体必须定义为全局变量或静态变量，然后在函数中给KP,KI,KD赋值
/************************采样周期未知且不变************************************/
//位置式PID
//pwm=Kp*e(k)+Ki*∑e(k)+Kd[e（k）-e(k-1)]
//setvalue : 设置值（期望值）
//actualvalue: 实际值
//由于全量输出，每次输出均与过去状态有关，计算时要对ek累加，计算量大
//PID_LocTypeDef Speed1Pid = {
//        .kp = 60,
//        .ki = 50,
//        .kd = 0,
//        .ek = 0,
//        .ek1 = 0,
//        .ek2 = 0,
//        .location_sum = 0,
//        .out = 0,

//};
//PID_LocTypeDef Speed2Pid = {
//        .kp = 60,
//        .ki = 50,
//        .kd = 0,
//        .ek = 0,
//        .ek1 = 0,
//        .ek2 = 0,
//        .location_sum = 0,
//        .out = 0,

//};

//PID_LocTypeDef TurnPid = {
//        .kp = 30,
//        .ki = 0,
//        .kd = 0,
//        .ek = 0,
//        .ek1 = 0,
//        .ek2 = 0,
//        .location_sum = 0,
//        .out = 0,

//};


float PID_location(float setvalue, float actualvalue, PSpeedPIDControl_Struct PID)
{
    PID->ek =setvalue-actualvalue;
    PID->location_sum += PID->ek;                         //计算累计误差值
    if((PID->ki!=0)&&(PID->location_sum>(PID_LIMIT_MAX/PID->ki))) PID->location_sum=PID_LIMIT_MAX/PID->ki;
    if((PID->ki!=0)&&(PID->location_sum<(PID_LIMIT_MIN/PID->ki))) PID->location_sum=PID_LIMIT_MIN/PID->ki;//积分限幅

  PID->out=PID->kp*PID->ek+(PID->ki*PID->location_sum)+PID->kd*(PID->ek-PID->ek1);
  PID->ek1 = PID->ek;
    if(PID->out<PID_LIMIT_MIN)  PID->out=PID_LIMIT_MIN;
    if(PID->out>PID_LIMIT_MAX)  PID->out=PID_LIMIT_MAX;//PID->out限幅

    return PID->out;
}
//增量式PID
//pidout+=Kp[e（k）-e(k-1)]+Ki*e(k)+Kd[e(k)-2e(k-1)+e(k-2)]
//setvalue : 设置值（期望值）
//actualvalue: 实际值
float PID_increment(float setvalue, float actualvalue, PSpeedPIDControl_Struct PID)
{
    PID->ek =setvalue-actualvalue;
  PID->out+=PID->kp*(PID->ek-PID->ek1)+PID->ki*PID->ek+PID->kd*(PID->ek-2*PID->ek1+PID->ek2);
//  PID->out+=PID->kp*PID->ek-PID->ki*PID->ek1+PID->kd*PID->ek2;
  PID->ek2 = PID->ek1;
  PID->ek1 = PID->ek;

    if(PID->out<PID_LIMIT_MIN)  PID->out=PID_LIMIT_MIN;
    if(PID->out>PID_LIMIT_MAX)  PID->out=PID_LIMIT_MAX;//限幅

    return PID->out;
}
PID_LocTypeDef Turn_Pid = {

    .kp = 3.25f,

    .ki = 0.0f,

    .kd = 0.0f,

    .ek = 0.0f,

    .ek1 = 0.0f,

    .ek2 = 0.0f,

    .location_sum = 0.0f,

    .out = 0.0f,

};





PID_LocTypeDef anglePID;

PID_LocTypeDef speedLPID = {

    .kp = 35.0f,

    .ki = 0.0f,

    .kd = 1.0f,

    .ek = 0.0f,

    .ek1 = 0.0f,

    .ek2 = 0.0f,

    .location_sum = 0.0f,

    .out = 0.0f,

};

PID_LocTypeDef speedRPID = {

    .kp = 35.0f,

    .ki = 0.0f,

    .kd = 1.0f,

    .ek = 0.0f,

    .ek1 = 0.0f,

    .ek2 = 0.0f,

    .location_sum = 0.0f,

    .out = 0.0f,

};





float Velocity_Kp=35,Velocity_Ki=0.0,Velocity_Kd=1.0;		//速度环 

float Turn_Kp=3.25,Turn_Kd=0;							//转向环



static void PID_UpdateGains(PID_LocTypeDef *pid, float kp, float ki, float kd)

{

    if(pid == NULL)

    {

        return;

    }

    pid->kp = kp;

    pid->ki = ki;

    pid->kd = kd;

}



int Velocity(float Target, float actual, PID_LocTypeDef *pid)

{

    if(pid == NULL)

    {

        return 0;

    }



    PID_UpdateGains(pid, Velocity_Kp, Velocity_Ki, Velocity_Kd);

    return (int)PID_location(Target, actual, pid);

}





   // PID_UpdateGains(pid, Velocity_Kp, Velocity_Ki, Velocity_Kd);

    //int Velocity(int Target,int encoder)
//{
//	static int Err_LowOut_last,Encoder_S;
//	static float a=0.7;
//	int Err,Err_LowOut,temp;
////	Velocity_Ki=Velocity_Kp/200;
//	//1、计算偏差值
//	Err=encoder-Target;
//	//2、低通滤波
//	Err_LowOut=(1-a)*Err+a*Err_LowOut_last;
//	Err_LowOut_last=Err_LowOut;
//	//3、积分
//	Encoder_S+=Err_LowOut;
//	//4、积分限幅(-20000~20000)
//	Encoder_S=Encoder_S>10000?10000:(Encoder_S<(-10000)?(-10000):Encoder_S);
//	
//	//5、速度环计算
//	temp=Velocity_Kp*Err_LowOut+Velocity_Ki*Encoder_S;
//	return temp;
//}


int Turn(float targetYaw,float currentYaw)

{

    PID_UpdateGains(&Turn_Pid, Turn_Kp, 0.0f, Turn_Kd);

    return (int)PID_location(targetYaw, currentYaw, &Turn_Pid);

}



int angleOutput;

float targetSpeedL;

float targetSpeedR;



// void cascadeControl(

//                    float targetYaw,

//                    float baseSpeed,

//                    float currentYaw,

//                    float EncoderLeft,

//                    float EncoderRight,

//                    int* MotorL,

//                    int* MotorR) {

//     angleOutput = Turn(targetYaw, currentYaw);



//     targetSpeedL = baseSpeed - angleOutput;

//     targetSpeedR = baseSpeed + angleOutput;



//     if(MotorL != NULL) {

//         *MotorL = Velocity(targetSpeedL, EncoderLeft, &speedLPID);

//     }

//     if(MotorR != NULL) {

//         *MotorR = Velocity(targetSpeedR, EncoderRight, &speedRPID);

//     }

// }

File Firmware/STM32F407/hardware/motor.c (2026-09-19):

#include "motor.h"

/* ==================== 宏定义 ==================== */
// 定时器句柄定义
#define PWM_TIM1    htim1
#define EXTI_TIM1    htim4
// PWM 最大限幅（与你的ARR匹配）
#define PWM_MAX     8000

/* ==================== 静态函数声明 ==================== */
// 内部辅助函数：设置GPIO方向
static void Motor_SetDir(GPIO_TypeDef *port, uint16_t pin1, uint16_t pin2, GPIO_PinState state1, GPIO_PinState state2);

/* ==================== 对外接口函数 ==================== */

/**
  * @brief  电机驱动初始化
  * @param  无
  * @retval 无
  */
void Motor_Init(void)
{
    /* 开启定时器更新中断 */
    __HAL_TIM_ENABLE_IT(&EXTI_TIM1, TIM_IT_UPDATE);
    /* 启动PWM输出通道 */
    HAL_TIM_PWM_Start(&PWM_TIM1, TIM_CHANNEL_3);
    HAL_TIM_PWM_Start(&PWM_TIM1, TIM_CHANNEL_4);

    /* 初始化所有电机方向引脚为复位状态 */
    HAL_GPIO_WritePin(GPIOC, GPIO_PIN_2 | GPIO_PIN_3  , GPIO_PIN_RESET);
	  HAL_GPIO_WritePin(GPIOA, GPIO_PIN_4 | GPIO_PIN_5  , GPIO_PIN_RESET);
}

/**
  * @brief  电机1控制（右）
  * @param  Compare: PWM占空比（正负表示方向）
  * @retval 无
  */
void M1_left(int32_t Compare)
{
    // 限幅处理
    if(Compare > PWM_MAX) Compare = PWM_MAX;
    if(Compare < -PWM_MAX) Compare = -PWM_MAX;

    if(Compare >= 0)
    {
        __HAL_TIM_SET_COMPARE(&PWM_TIM1, TIM_CHANNEL_3, Compare);
        Motor_SetDir(GPIOC, GPIO_PIN_2, GPIO_PIN_3, GPIO_PIN_SET, GPIO_PIN_RESET);
    }
    else
    {
        __HAL_TIM_SET_COMPARE(&PWM_TIM1, TIM_CHANNEL_3, -Compare);
        Motor_SetDir(GPIOC, GPIO_PIN_2, GPIO_PIN_3, GPIO_PIN_RESET, GPIO_PIN_SET);
    }
}

/**
  * @brief  电机2控制（左）
  * @param  Compare: PWM占空比（正负表示方向）
  * @retval 无
  */
void M2_right(int32_t Compare)
{
    if(Compare > PWM_MAX) Compare = PWM_MAX;
    if(Compare < -PWM_MAX) Compare = -PWM_MAX;

    if(Compare >= 0)
    {
        __HAL_TIM_SET_COMPARE(&PWM_TIM1, TIM_CHANNEL_4, Compare);
        Motor_SetDir(GPIOA, GPIO_PIN_4, GPIO_PIN_5, GPIO_PIN_SET, GPIO_PIN_RESET);
    }
    else
    {
        __HAL_TIM_SET_COMPARE(&PWM_TIM1, TIM_CHANNEL_4, -Compare);
        Motor_SetDir(GPIOA, GPIO_PIN_4, GPIO_PIN_5, GPIO_PIN_RESET, GPIO_PIN_SET);
    }
}



/* ==================== 静态内部函数 ==================== */

/**
  * @brief  电机方向引脚设置（内部复用函数）
  */
static void Motor_SetDir(GPIO_TypeDef *port, uint16_t pin1, uint16_t pin2, GPIO_PinState state1, GPIO_PinState state2)
{
    HAL_GPIO_WritePin(port, pin1, state1);
    HAL_GPIO_WritePin(port, pin2, state2);
}

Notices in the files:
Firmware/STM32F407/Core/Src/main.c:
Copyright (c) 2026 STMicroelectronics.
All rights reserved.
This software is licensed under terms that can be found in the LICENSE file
